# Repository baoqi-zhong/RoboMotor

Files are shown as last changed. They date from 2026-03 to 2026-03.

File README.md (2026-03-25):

# RoboMotor

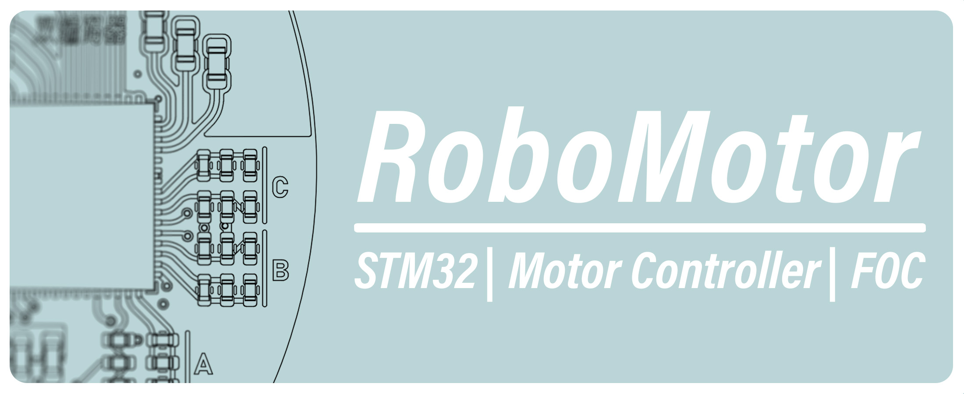
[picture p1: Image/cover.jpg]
Project cover


**English** | [中文版](./README_CN.md)

**RoboMotor** is an open-source FOC motor driver project. It provides integrated hardware designs and control algorithms for robotics applications.

## Key Features

- **Hardware Specs**: 4-to-6 layer PCBs designed for 20A-40A continuous current at 24V.
- **Control Algorithm**: Field-Oriented Control (FOC) with current, speed, and position loops.
- **Validation**: Designs tested in RoboMaster environments.

## Hardware

Designed with **KiCad 8**.
For detailed specifications, schematics, and measured performance, please visit the [Hardware](./Hardware/README.md) directory or click on a specific project below.

| Project Name | Target Motor | Key Specs | Core |
| :--- | :--- | :--- | :--- |
| [**RoboMotor-DJI-M3508**](./Hardware/RoboMotor-DJI-M3508/) | [DJI M3508](https://www.robomaster.com/en-US/products/components/general/M3508) | **24V 20A**, 6-Layer, Sin/Cos Encoder | STSPIN32G4 |
| [**RoboMotor-GIM6010-V2**](./Hardware/RoboMotor-GIM6010-V2/) | [GIM6010-8](https://steadywin-motor.com/products/built-in-star-gear-motor-motor-robot-joint-driver-actuator-controller-motor) | **24V 40A**, Dual Encoder Support | STSPIN32G4 |
| [**RoboMotor-GIM6010-V2-Encoder**](./Hardware/RoboMotor-GIM6010-V2-Encoder/) | GIM6010-8 | Magnetic Output Encoder PCB | MA730 |
| [**RoboMotor-GIM6010**](./Hardware/RoboMotor-GIM6010/) | GIM6010-8 | *Legacy Reference Design* | STM32G431 + FD6288 |

## Software

The FOC control algorithm is developed for the **STM32G4** series.

### Features
- **FOC Implementation**: Sensor-based Field-Oriented Control with Flux/Torque decoupling and BEMF feedforward compensation.
- **Control Loops**: 17Khz inner Current loop + outer 4Khz Speed loop + 1Khz Position loop.
- **Connectivity**:
  - **CAN Bus**: Compatible with DJI RoboMaster protocols (M3508/C620).
  - **Custom Protocol**: Extended commands for parameter tuning and telemetry.
- **Additional Functions**:
  - **Auto-Calibration**: Routines for encoder offset and motor parameter identification.
  - **Safety Mechanisms**: Error handling (Over-current, Over/under voltage, Over-temp) with auto-recovery modes.
  - **Feedback Support**: Support for SPI magnetic encoders and analog inputs.

*Find the source code and documentation in the `Software/` directory.*

## License

This project is released under the MIT License.  
See [LICENSE](./LICENSE) for details.

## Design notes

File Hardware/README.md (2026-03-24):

# RoboMotor Hardware
# Open-sourced FOC Driver PCB

All projects are designed with Kicad 8.

## Project List

|Name|Target Motor|Description|MCU/Chip|
|:--|:--|:--|:--|
|RoboMotor-DJI-M3508|[DJI M3508](https://www.robomaster.com/en-US/products/components/general/M3508)|6 Layer, High power density|STSPIN32G4|
|RoboMotor-GIM6010-V2|[GIM6010-8](https://steadywin-motor.com/products/built-in-star-gear-motor-motor-robot-joint-driver-actuator-controller-motor)|Support gear box output encoder|STSPIN32G4|
|RoboMotor-GIM6010-V2-Encoder|GIM6010-8|PCB of the output encoder|MA730|
|RoboMotor-GIM6010|GIM6010-8|Old version, reference only|STM32G431 + FD6288|

### RoboMotor-DJI-M3508

- Operating conditions: 24V, max 20A.
- MCU: STSPIN32G4. With integrated buck, LDO, Mosfet drivers and STM32G431 MCU.
- 6 Layer PCB, separate analog sampling circuit and power stage signals.
- Supports Sin/Cos encoder and CAN communication. Fully compatible with [DJI C620](https://www.robomaster.com/en-US/products/components/general/M3508) ESC.

Schematic:
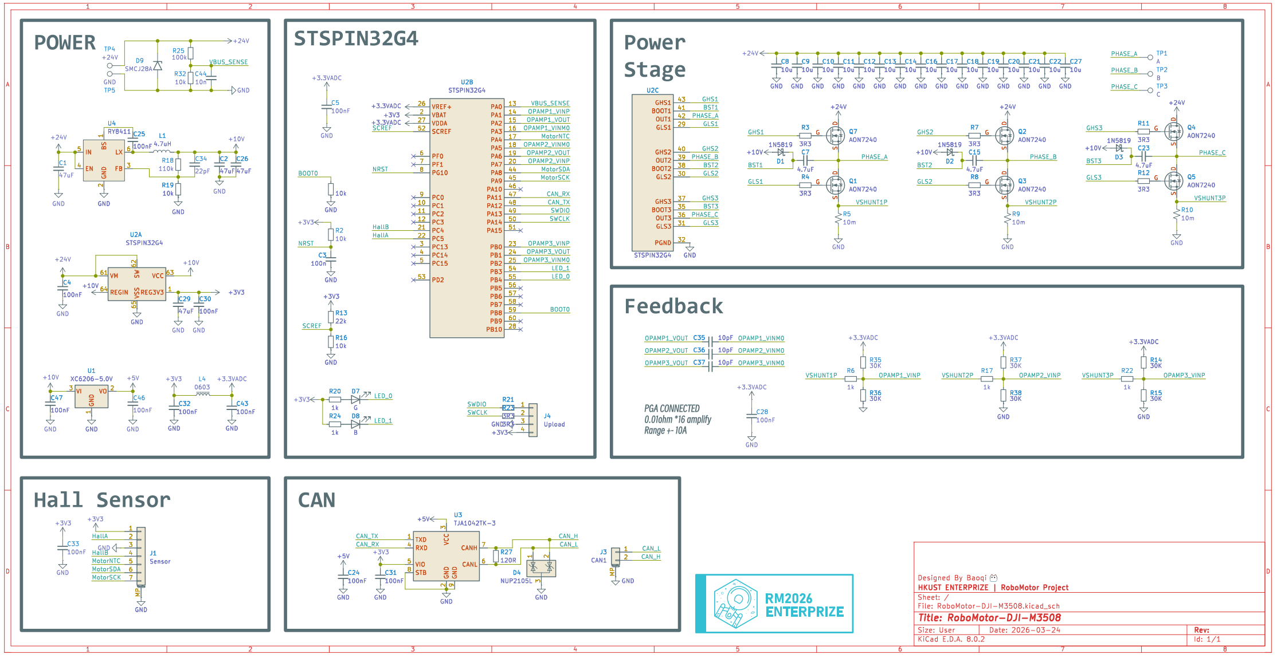
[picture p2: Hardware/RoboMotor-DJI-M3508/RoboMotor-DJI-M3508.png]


### RoboMotor-GIM6010-V2

- Operating conditions: 24V, max 40A.
- MCU: STSPIN32G4. With integrated buck, LDO, Mosfet drivers and STM32G431 MCU.
- Encoder: MA732 magnetic encoder
- 4 Layer PCB.
- Supports MA732 magnetic encoder, second encoder after gear box and CAN communication. Specifically designed for [GIM6010-8](https://steadywin-motor.com/products/built-in-star-gear-motor-motor-robot-joint-driver-actuator-controller-motor) motor with 8:1 reduction ratio.

Schematic:
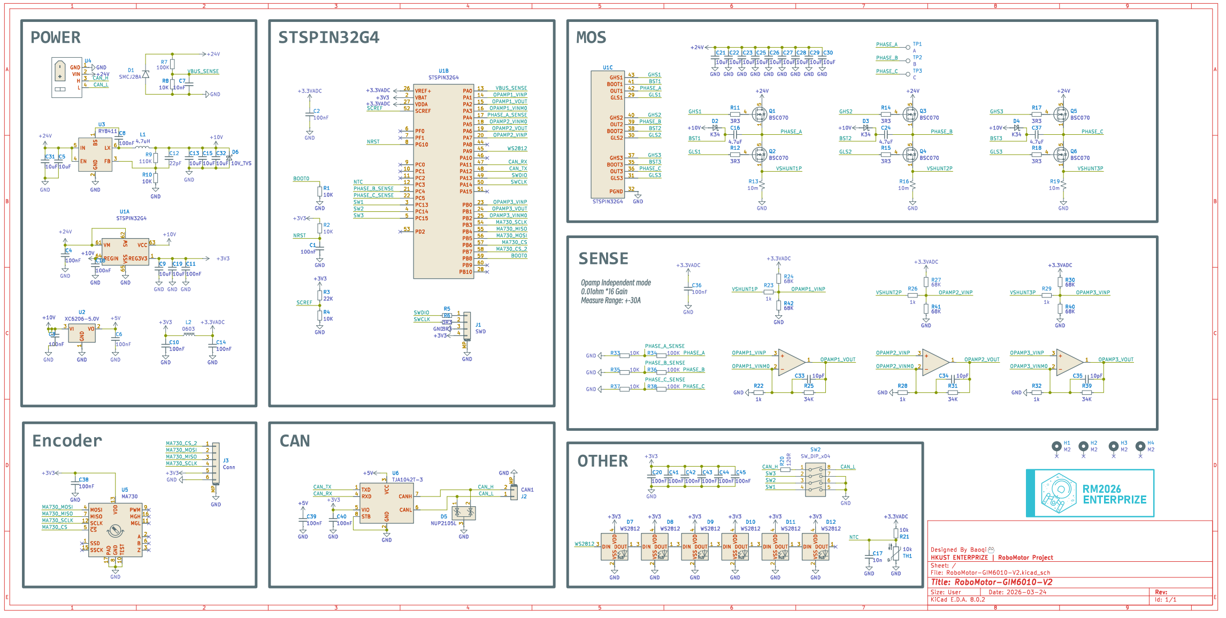
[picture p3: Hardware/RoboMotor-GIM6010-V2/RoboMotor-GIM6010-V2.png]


### RoboMotor-GIM6010
Lagecy version, for reference only.

- Operating conditions: 24V, max 40A.
- MCU: STM32G431CBU6. Mosfet driver: FD6288.
- Encoder: MA732 magnetic encoder
- 4 Layer PCB.
- Supports MA732 magnetic encoder, second encoder after gear box and CAN communication. Specifically designed for [GIM6010-8](https://steadywin-motor.com/products/built-in-star-gear-motor-motor-robot-joint-driver-actuator-controller-motor) motor with 8:1 reduction ratio.

Schematic:
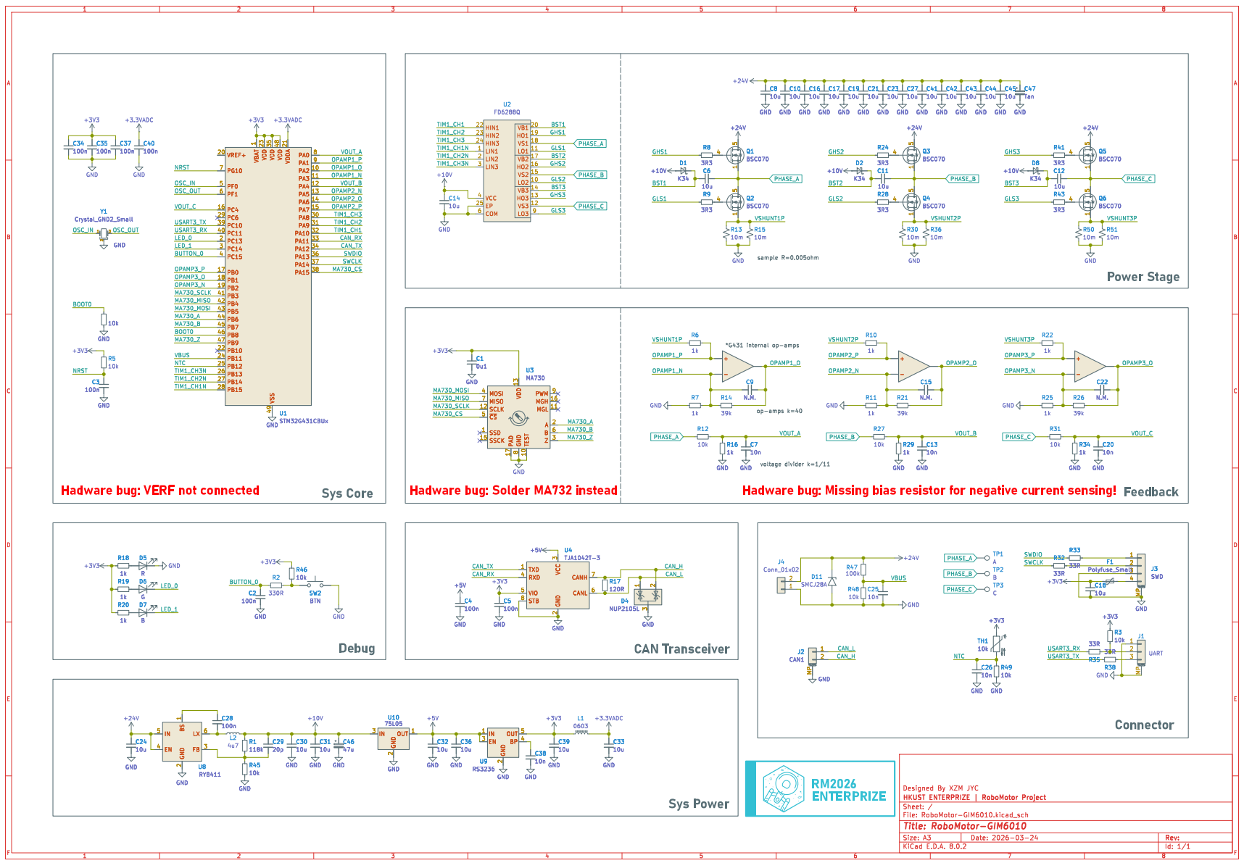
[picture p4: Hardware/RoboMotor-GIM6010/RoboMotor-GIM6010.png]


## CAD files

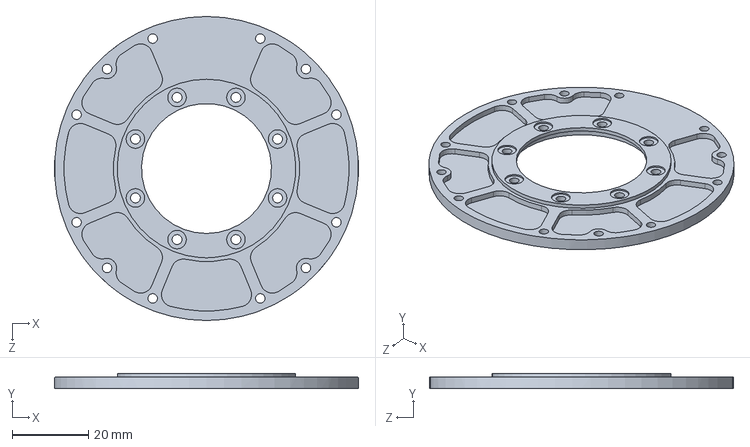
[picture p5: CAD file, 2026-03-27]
Mechanical/GIM6010/CNC_TOP.SLDPRT
80.0 x 4.00 x 80.0 mm

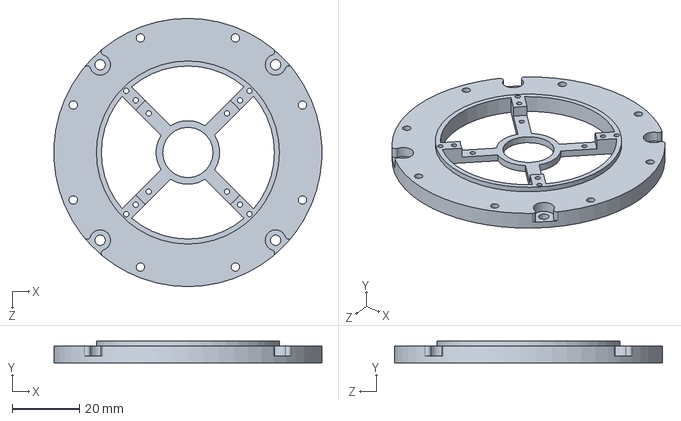
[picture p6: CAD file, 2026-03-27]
Mechanical/GIM6010/CNC_BOT.SLDPRT
79.9 x 6.50 x 80.0 mm

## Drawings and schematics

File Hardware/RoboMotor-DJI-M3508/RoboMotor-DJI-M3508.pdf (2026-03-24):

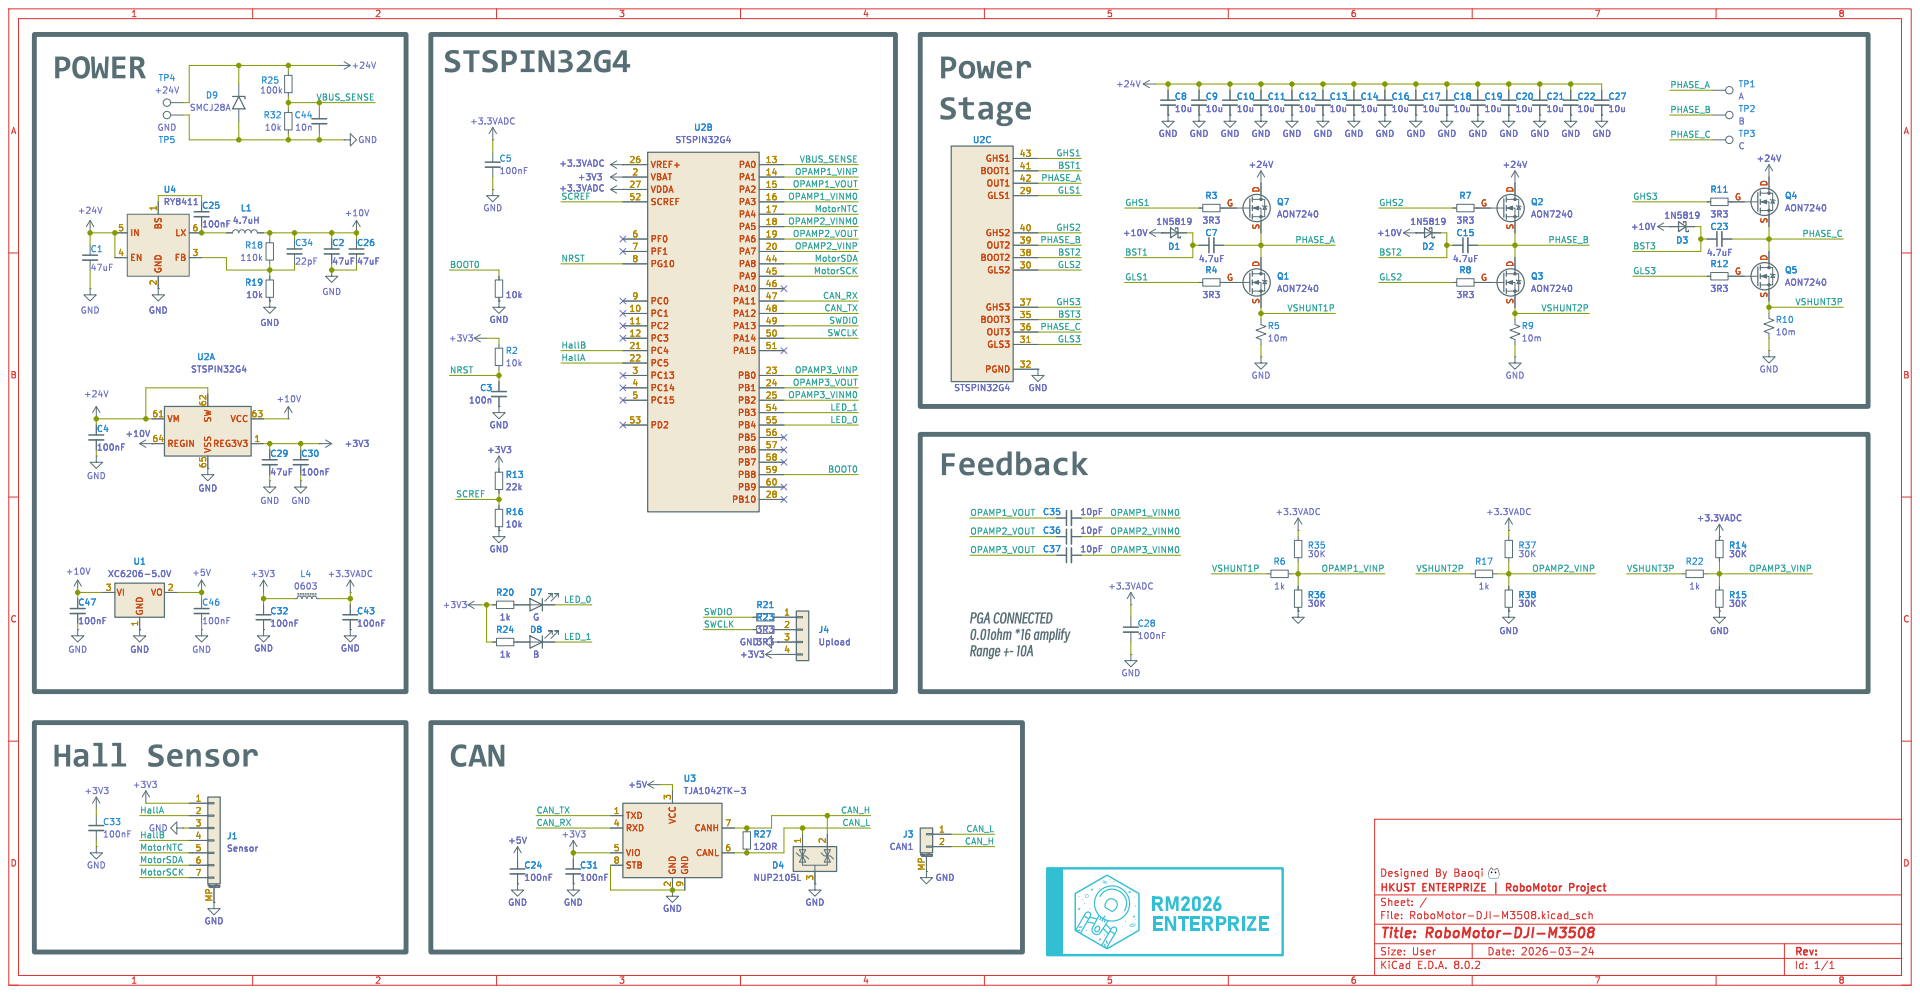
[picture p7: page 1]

CAN_RX MotorSCK MotorSDA CAN_TX OPAMP2_VOUT OPAMP2_VINM0 OPAMP3_VINP Hall Sensor

3 RXD 4 VIO 5 CANL 6 CANH 7 STB 8 GND

Id: 1/1 Title: RoboMotor-DJI-M3508

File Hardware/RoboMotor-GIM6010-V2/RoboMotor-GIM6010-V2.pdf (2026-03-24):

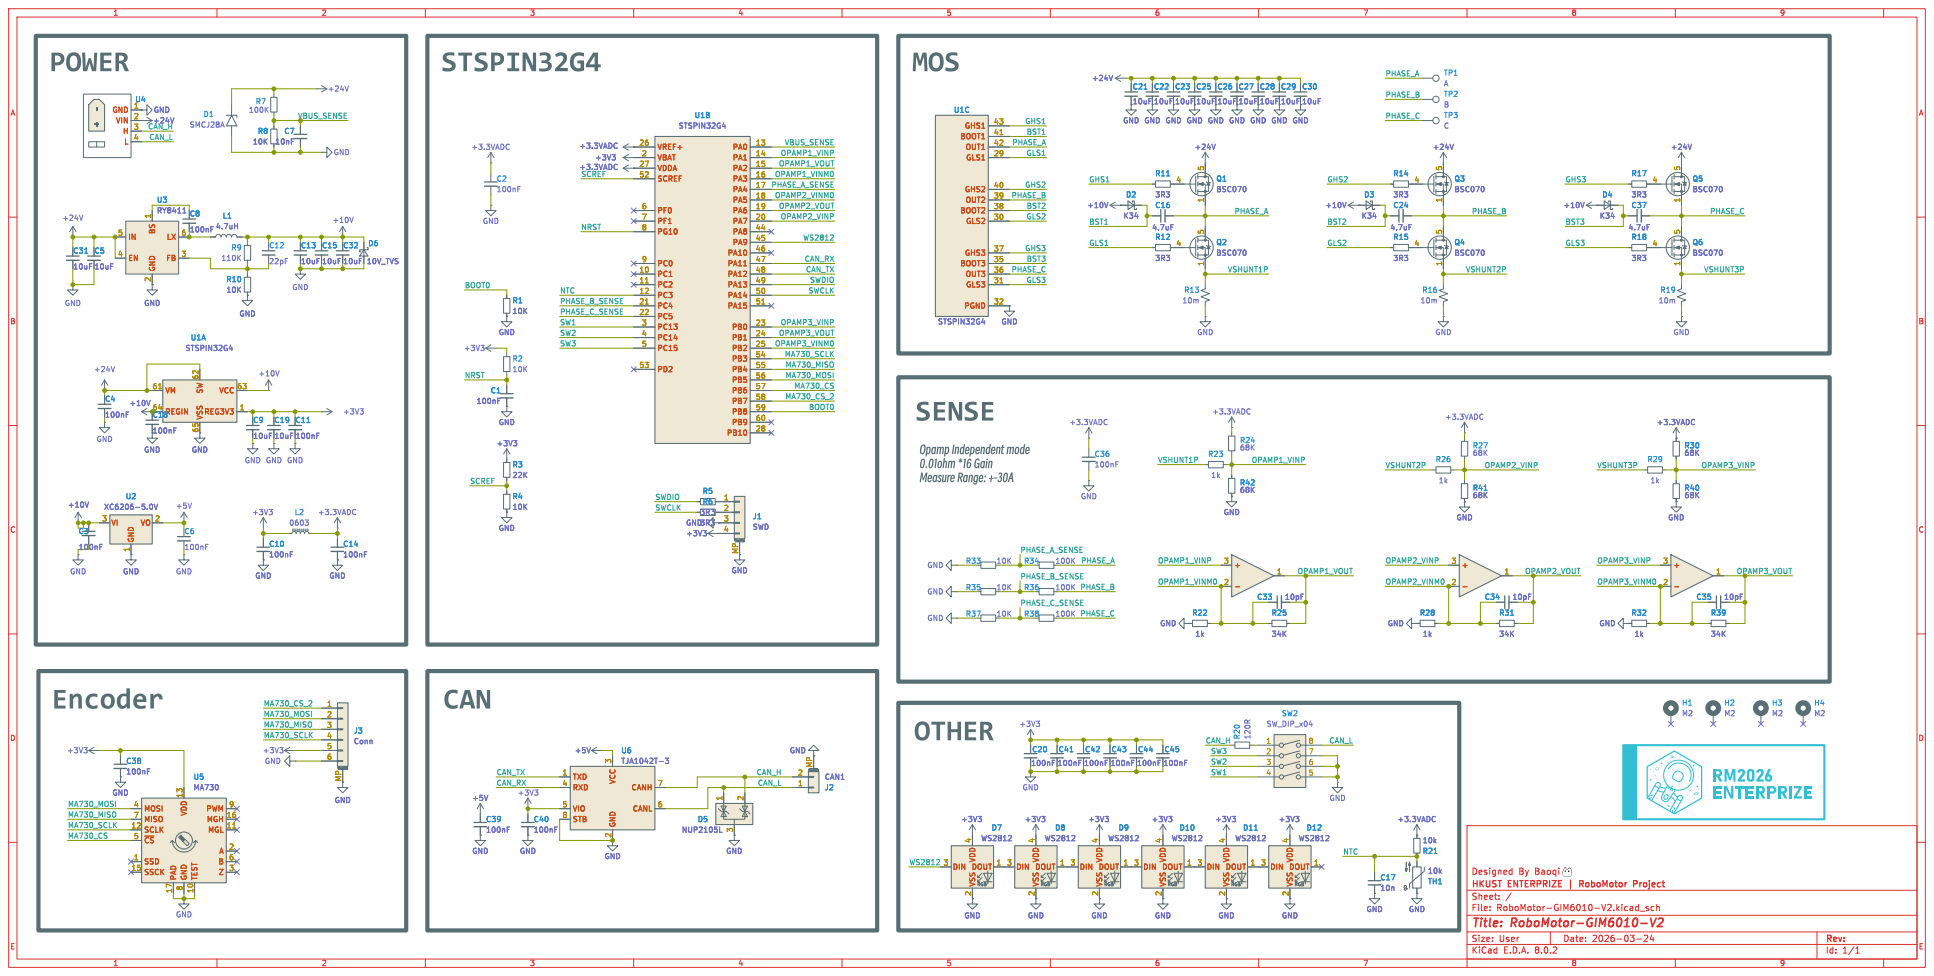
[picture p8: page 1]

3 RXD 4 VIO 5 CANL 6 CANH 7 STB 8 +5V GND

3 RXD 4 VIO 5 CANL 6 CANH 7 STB 8 U6 TJA1042T-3 +5V

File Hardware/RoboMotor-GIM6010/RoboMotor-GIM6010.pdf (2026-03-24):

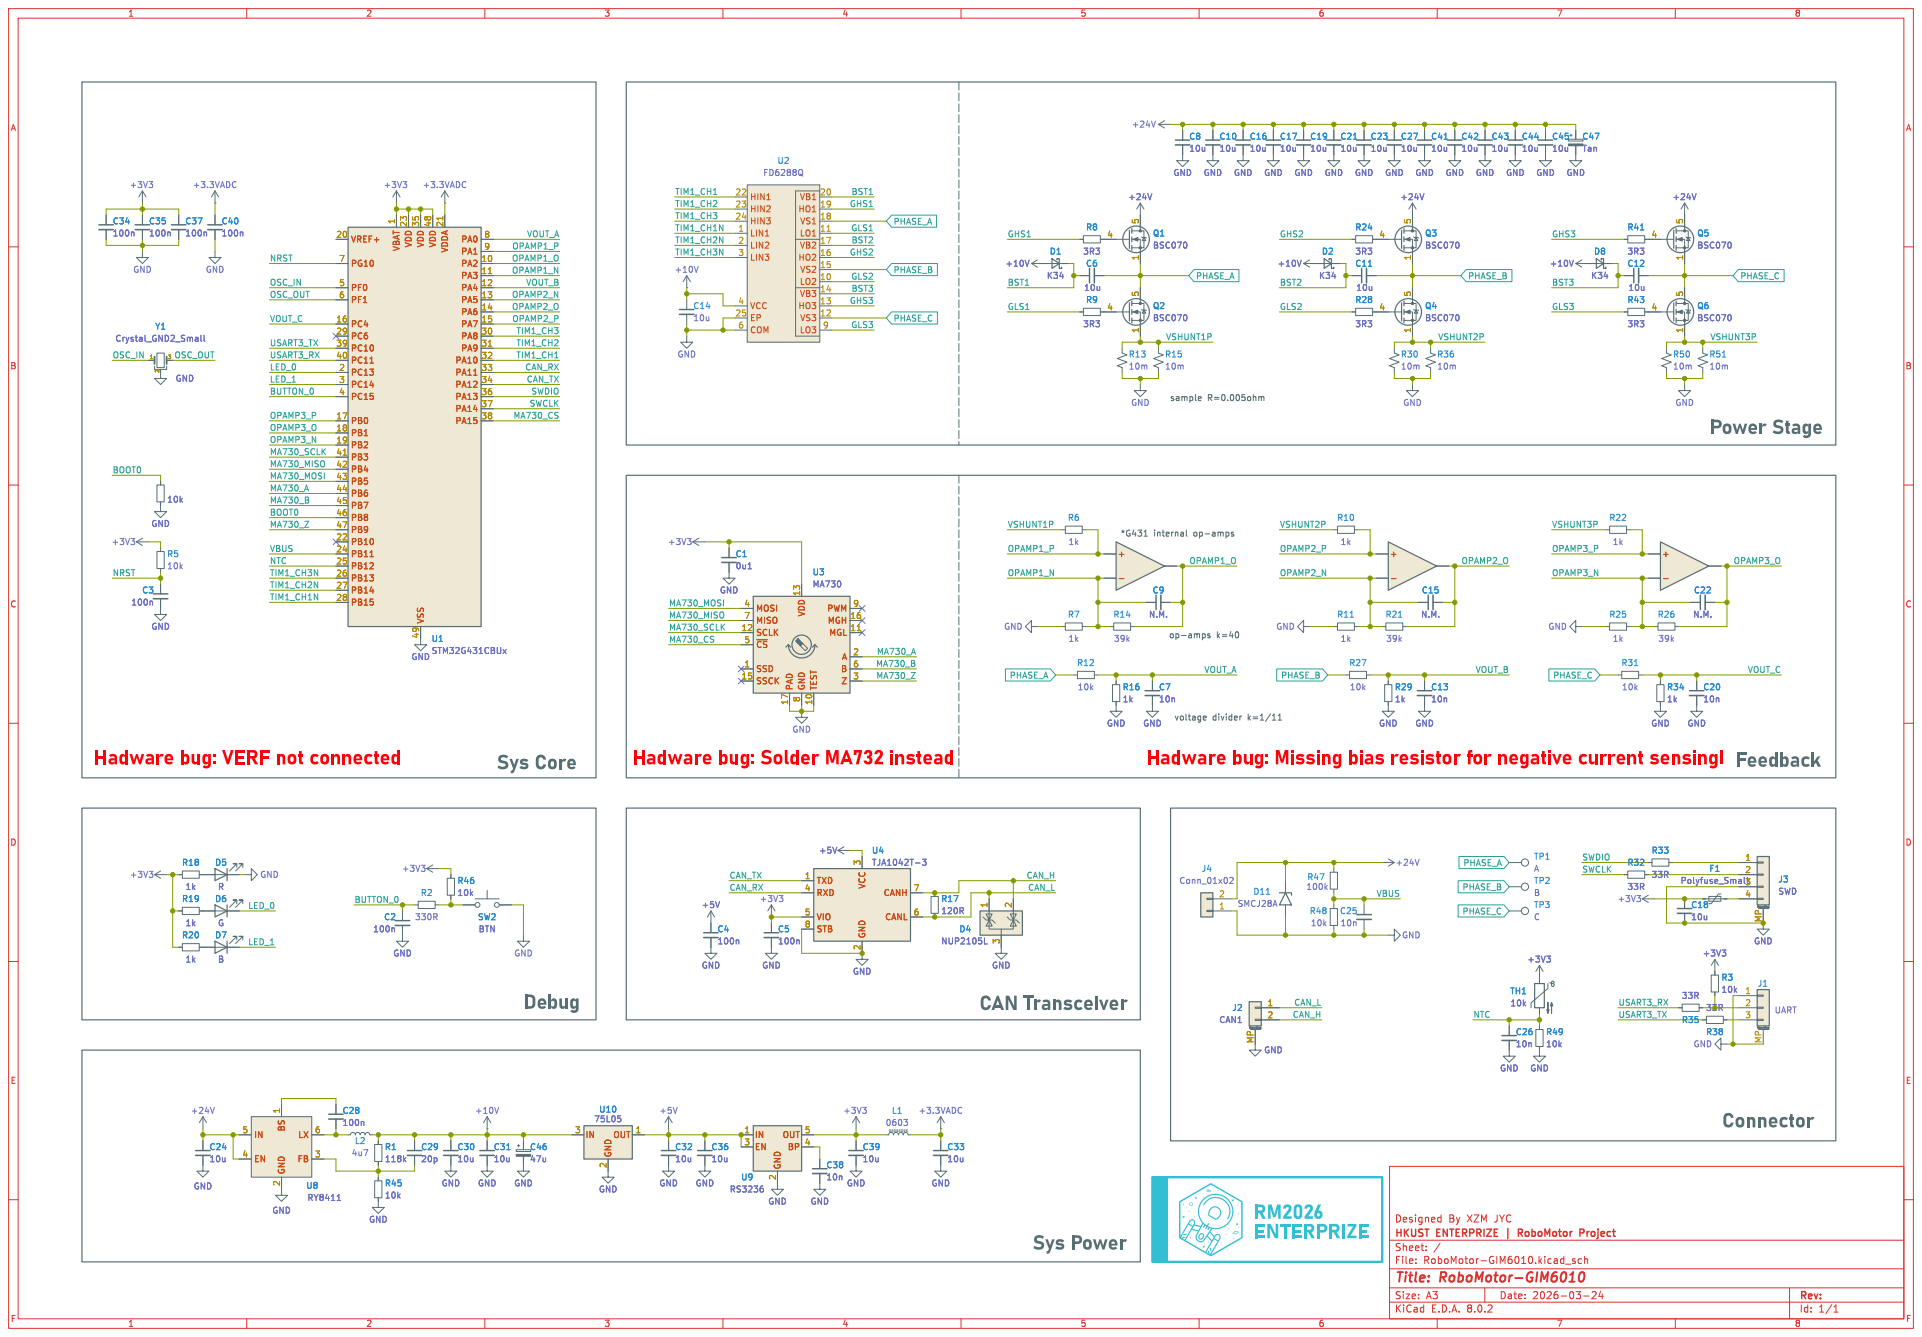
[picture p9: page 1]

1 PA2 10 PA3 11 PA4 12 PA5 13 PA6 14 PA7 15 PC4 16 PB0 17 PB1 18 PB2 19 PC13 2 VREF+ 20 VDDA 21 PB10 22 VDD 23 PB11 24 PB12 25 PB13 26 PB14 27 PB15 28 PC6 29 PC14 3 PA8 30 PA9 31 PA10 32 PA11 33 PA12 34 VDD 35 PA13 36 PA14 37 PA15 38 PC10 39 PC15 4 PC11 40 PB3 41 PB4 42 PB5 43 PB6 44 PB7 45 PB8 46 PB9 47 VDD 48 VSS 49 PF0 5 PF1 6 PG10 7 PA0 8 PA1 9 Y1 Crystal_GND2_Small 1

1 PA2 10 PA3 11 PA4 12 PA5 13 PA6 14 PA7 15 PC4 16 PB0 17 PB1 18 PB2 19 PC13 2 VREF+ 20 VDDA 21 PB10 22 VDD 23 PB11 24 PB12 25 PB13 26 PB14 27 PB15 28 PC6 29 PC14 3 PA8 30 PA9 31 PA10 32 PA11 33 PA12 34 VDD 35 PA13 36 PA14 37 PA15 38 PC10 39 PC15 4 PC11 40 PB3 41 PB4 42 PB5 43 PB6 44 PB7 45 PB8 46 PB9 47 VDD 48 VSS 49 PF0 5 PF1 6 PG10 7 PA0 8 PA1 9 U1STM32G431CBUx R5

Hadwarebug:Missingbiasresistorfor negativecurrent sensing!

3 RXD 4 VIO 5 CANL 6 CANH 7 STB 8 U4 TJA1042T-3

3 RXD 4 VIO 5 CANL 6 CANH 7 STB 8 D4 NUP2105L 3

2 EN 3 BP 4 OUT 5 U9 RS3236 GND GND
10u GND

2 EN 3 BP 4 OUT 5 GND GND

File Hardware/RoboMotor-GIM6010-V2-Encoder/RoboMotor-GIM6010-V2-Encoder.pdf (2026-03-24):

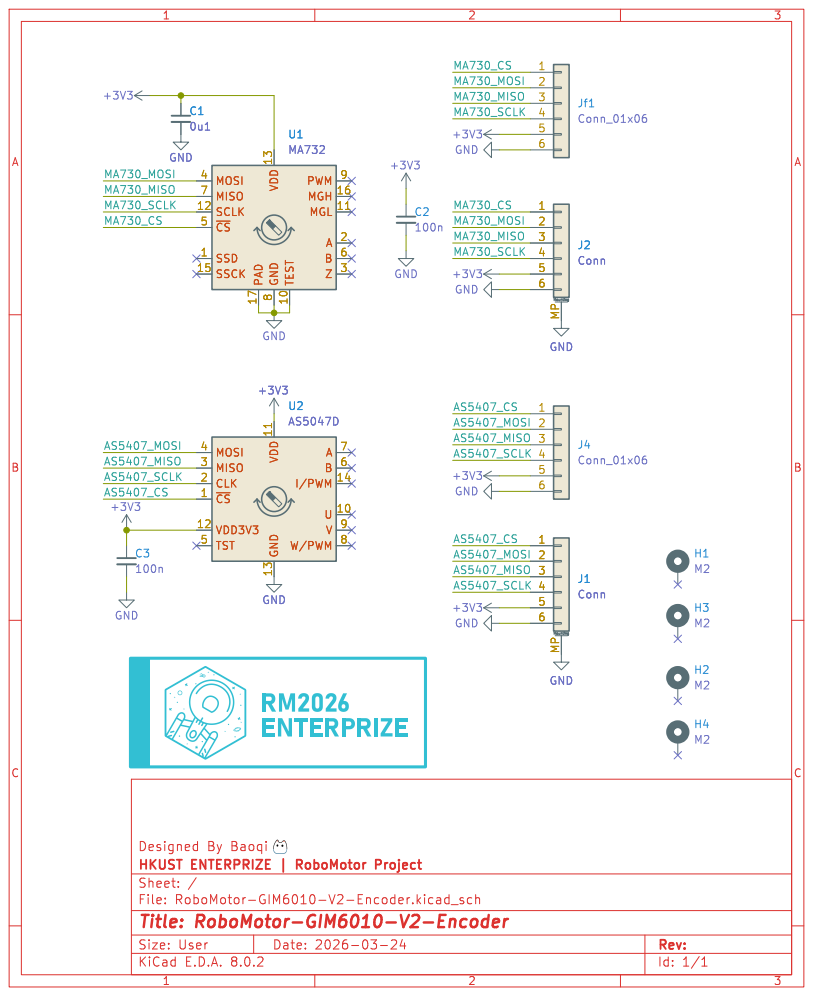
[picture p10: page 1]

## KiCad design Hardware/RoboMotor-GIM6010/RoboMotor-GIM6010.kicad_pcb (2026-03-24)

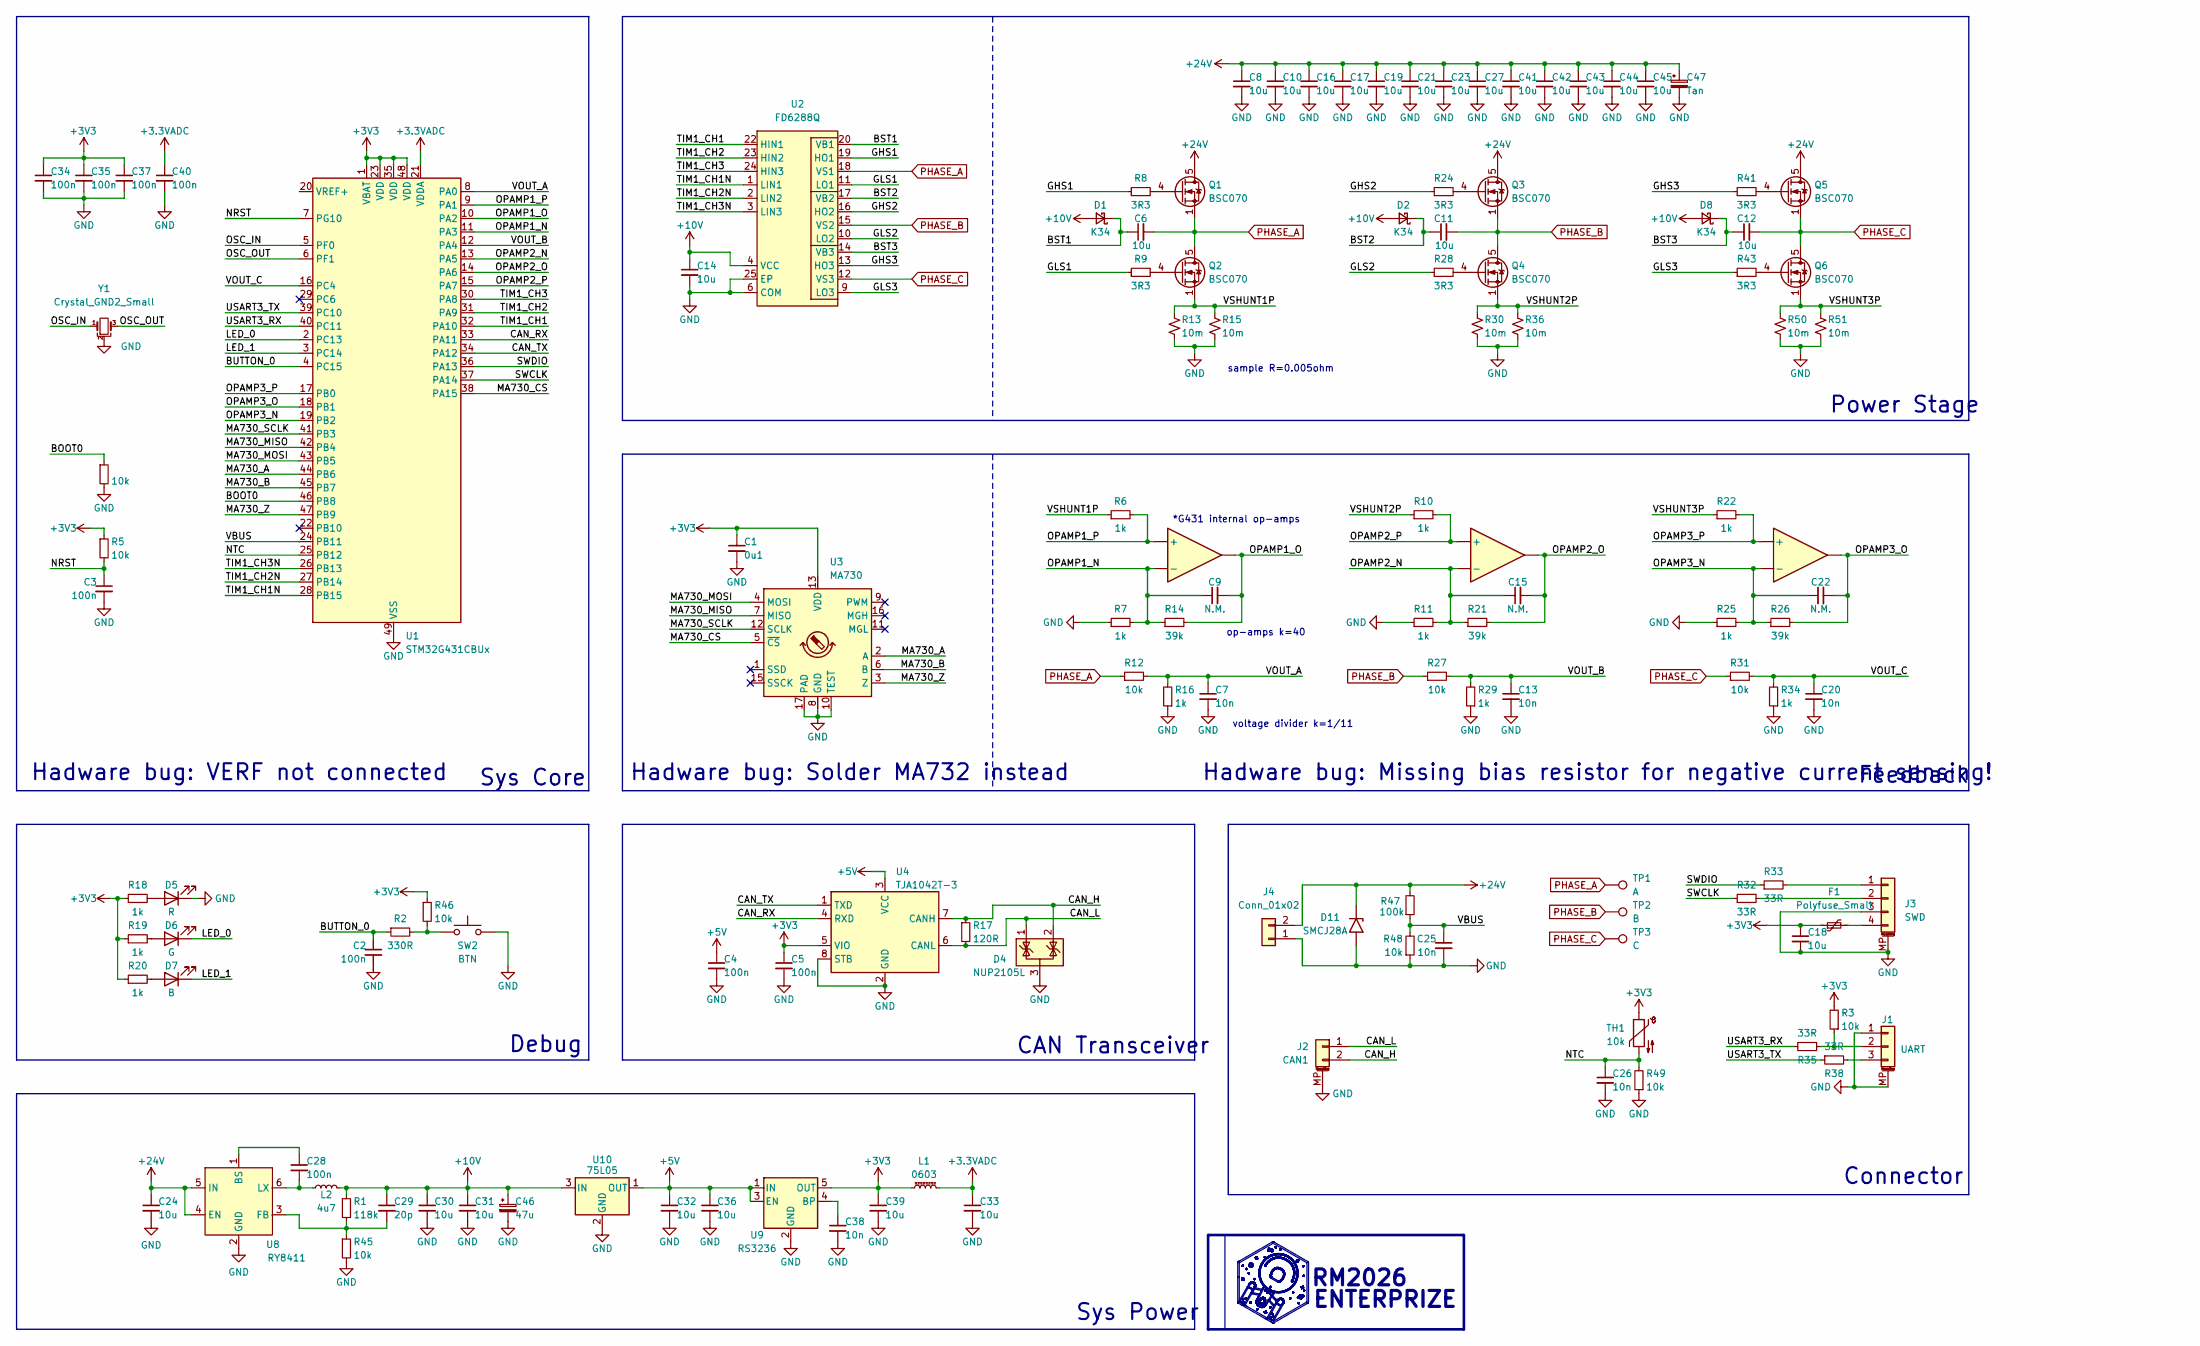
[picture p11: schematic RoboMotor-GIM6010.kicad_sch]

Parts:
C1: 0u1; C_0603_1608Metric
C2, C3, C4, C5, C28, C34, C35, C37, C40: 100n; C_0603_1608Metric
C6, C11, C12, C14, C18, C32, C33, C36, C39: 10u; C_0603_1608Metric
C7, C13, C20, C25, C26, C38: 10n; C_0603_1608Metric
C8, C10, C16, C17, C19, C21, C23, C24, C27, C30, C31, C41, C42, C43, C44, C45: 10u; C_1206_3216Metric
C9, C15, C22: N.M.; C_0603_1608Metric
C29: 20p; C_0603_1608Metric
C46: 47u; CP_EIA-3216-18_Kemet-A_Pad1.58x1.35mm_HandSolder
C47: Tan; CP_EIA-7343-30_AVX-N
D1, D2, D8: K34; D_SOD-323_HandSoldering
D4: NUP2105L; SOT-23
D5: R; LED_Side_0802
D6: G; LED_Side_0802
D7: B; LED_Side_0802
D11: SMCJ28A; D_SMC
F1: Polyfuse_Small; Fuse_1206_3216Metric
J1: UART; JST_GH_SM03B-GHS-TB_1x03-1MP_P1.25mm_Horizontal
J2: CAN1; JST_GH_SM02B-GHS-TB_1x02-1MP_P1.25mm_Horizontal
J3: SWD; Molex_PicoBlade_53261-0471_1x04-1MP_P1.25mm_Horizontal
J4: Conn_01x02; AMASS_XT30PW-M_1x02_P2.50mm_Horizontal
L1: 0603; L_0603_1608Metric
L2: 4u7; L_Sunlord_MWSA0402S
Q1, Q2, Q3, Q4, Q5, Q6: BSC070; TDSON-8-1
R1: 118k; R_0603_1608Metric
R2: 330R; R_0603_1608Metric
R3, R4, R5, R12, R27, R31, R45, R46, R48, R49: 10k; R_0603_1608Metric
R6, R7, R10, R11, R16, R18, R19, R20, R22, R25, R29, R34: 1k; R_0603_1608Metric
R8, R9, R24, R28, R41, R43: 3R3; R_0603_1608Metric
R13, R15, R30, R36, R50, R51: 10m; R_1206_3216Metric
R14, R21, R26: 39k; R_0603_1608Metric
R17: 120R; R_0603_1608Metric
R32, R33, R35, R38: 33R; R_0603_1608Metric
R47: 100k; R_0603_1608Metric
SW2: BTN; Panasonic_EVQPUL_EVQPUC
TH1: 10k; TestPoint_2Pads_Pitch2.54mm_Drill0.8mm
TP1: A; TestPoint_Pad_4.0x4.0mm
TP2: B; TestPoint_Pad_4.0x4.0mm
TP3: C; TestPoint_Pad_4.0x4.0mm
U1: STM32G431CBUx; QFN-48-1EP_7x7mm_P0.5mm_EP5.6x5.6mm
U2: FD6288Q; QFN-24-1EP_4x4mm_P0.5mm_EP2.7x2.7mm
U3: MA730; QFN-16-1EP_3x3mm_P0.5mm_EP1.75x1.75mm
U4: TJA1042T-3; SOIC-8_3.9x4.9mm_P1.27mm
U5, U6, U7: type="X" model="OPAMP" lib=""
U8: RY8411; SOT-23-6
U9: RS3236; SOT-23-5
U10: 75L05; SOT-89-3
Y1: Crystal_GND2_Small; Resonator_SMD_Murata_CSTxExxV-3Pin_3.0x1.1mm

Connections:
+3.3VADC: C33.1, C40.1, L1.2, U1.21 (VDDA)
+3V3: C1.1, C5.1, C18.1, C34.1, C35.1, C37.1, C39.1, F1.1, L1.1, R3.2, R5.1, R18.1, R19.1, R20.1, R46.1, TH1.1, U1.1 (VBAT), U1.23 (VDD), U1.35 (VDD), U1.48 (VDD), U3.13 (VDD), U4.5 (VIO), U9.5 (OUT)
+5V: C4.1, C32.1, C36.1, U4.3 (VCC), U9.1 (IN), U9.3 (EN), U10.1 (OUT)
+10V: C14.1, C29.1, C30.1, C31.1, C46.1, D1.2 (A), D2.2 (A), D8.2 (A), L2.2, R1.1, U2.4 (VCC), U10.3 (IN)
+24V: C8.1, C10.1, C16.1, C17.1, C19.1, C21.1, C23.1, C24.1, C27.1, C41.1, C42.1, C43.1, C44.1, C45.1, C47.1, D11.1 (A1), J4.2, Q1.5 (D), Q3.5 (D), Q5.5 (D), R47.2, U8.4 (EN), U8.5 (IN)
/BOOT0: R4.1, U1.46 (PB8)
/BST1: C6.1, D1.1 (K), U2.20 (VB1)
/BST2: C11.1, D2.1 (K), U2.17 (VB2)
/BST3: C12.1, D8.1 (K), U2.14 (VB3)
/BUTTON_0: C2.1, R2.1, U1.4 (PC15)
/CAN_H: D4.2 (K), J2.2, R17.1, U4.7 (CANH)
/CAN_L: D4.1 (K), J2.1, R17.2, U4.6 (CANL)
/CAN_RX: U1.33 (PA11), U4.4 (RXD)
/CAN_TX: U1.34 (PA12), U4.1 (TXD)
/GHS1: R8.1, U2.19 (HO1)
/GHS2: R24.1, U2.16 (HO2)
/GHS3: R41.1, U2.13 (HO3)
/GLS1: R9.1, U2.11 (LO1)
/GLS2: R28.1, U2.10 (LO2)
/GLS3: R43.1, U2.9 (LO3)
/LED_0: D6.1 (K), U1.2 (PC13)
/LED_1: D7.1 (K), U1.3 (PC14)
/MA730_A: U1.44 (PB6), U3.2 (A)
/MA730_B: U1.45 (PB7), U3.6 (B)
/MA730_CS: U1.38 (PA15), U3.5 (~CS)
/MA730_MISO: U1.42 (PB4), U3.7 (MISO)
/MA730_MOSI: U1.43 (PB5), U3.4 (MOSI)
/MA730_SCLK: U1.41 (PB3), U3.12 (SCLK)
/MA730_Z: U1.47 (PB9), U3.3 (Z)
/NRST: C3.1, R5.2, U1.7 (PG10)
/NTC: C26.1, R49.2, TH1.2, U1.25 (PB12)
/OPAMP1_N: C9.1, R7.2, R14.1, U1.11 (PA3), U5.
/OPAMP1_O: C9.2, R14.2, U1.10 (PA2), U5.
/OPAMP1_P: R6.2, U1.9 (PA1), U5.
/OPAMP2_N: C15.1, R11.2, R21.1, U1.13 (PA5), U6.
/OPAMP2_O: C15.2, R21.2, U1.14 (PA6), U6.
/OPAMP2_P: R10.2, U1.15 (PA7), U6.
/OPAMP3_N: C22.1, R25.2, R26.1, U1.19 (PB2), U7.
/OPAMP3_O: C22.2, R26.2, U1.18 (PB1), U7.
/OPAMP3_P: R22.2, U1.17 (PB0), U7.
/OSC_IN: U1.5 (PF0), Y1.1
/OSC_OUT: U1.6 (PF1), Y1.3
/SWCLK: R32.1, U1.37 (PA14)
/SWDIO: R33.1, U1.36 (PA13)
/TIM1_CH1: U1.32 (PA10), U2.22 (HIN1)
/TIM1_CH1N: U1.28 (PB15), U2.1 (LIN1)
/TIM1_CH2: U1.31 (PA9), U2.23 (HIN2)
/TIM1_CH2N: U1.27 (PB14), U2.2 (LIN2)
/TIM1_CH3: U1.30 (PA8), U2.24 (HIN3)
/TIM1_CH3N: U1.26 (PB13), U2.3 (LIN3)
/USART3_RX: R35.1, U1.40 (PC11)
/USART3_TX: R38.1, U1.39 (PC10)
/VBUS: C25.1, R47.1, R48.2, U1.24 (PB11)
/VOUT_A: C7.1, R12.2, R16.2, U1.8 (PA0)
/VOUT_B: C13.1, R27.2, R29.2, U1.12 (PA4)
/VOUT_C: C20.1, R31.2, R34.2, U1.16 (PC4)
/VSHUNT1P: Q2.1 (S), Q2.2 (S), Q2.3 (S), R6.1, R13.1, R15.1
/VSHUNT2P: Q4.1 (S), Q4.2 (S), Q4.3 (S), R10.1, R30.1, R36.1
/VSHUNT3P: Q6.1 (S), Q6.2 (S), Q6.3 (S), R22.1, R50.1, R51.1
GND: C1.2, C2.2, C3.2, C4.2, C5.2, C7.2, C8.2, C10.2, C13.2, C14.2, C16.2, C17.2, C18.2, C19.2, C20.2, C21.2, C23.2, C24.2, C25.2, C26.2, C27.2, C30.2, C31.2, C32.2, C33.2, C34.2, C35.2, C36.2, C37.2, C38.2, C39.2, C40.2, C41.2, C42.2, C43.2, C44.2, C45.2, C46.2, C47.2, D4.3 (A), D5.1 (K), D11.2 (A2), J1.1, J1.MP (MountPin), J2.MP (MountPin), J3.3, J3.MP (MountPin), J4.1, R4.2, R7.1, R11.1, R13.2, R15.2, R16.1, R25.1, R29.1, R30.2, R34.1, R36.2, R45.2, R48.1, R49.1, R50.2, R51.2, SW2.2, U1.49 (VSS), U2.6 (COM), U2.25 (EP), U3.8 (GND), U3.10 (TEST), U3.17 (PAD), U4.2 (GND), U4.8 (STB), U8.2 (GND), U9.2 (GND), U10.2 (GND), Y1.2
unnamed: D5.2 (A), R18.2
unnamed: D6.2 (A), R19.2
unnamed: D7.2 (A), R20.2
unnamed: J1.2, R3.1, R35.2
unnamed: J1.3, R38.2
unnamed: J3.1, R33.2
unnamed: J3.2, R32.2
unnamed: F1.2, J3.4
unnamed: Q1.4 (G), R8.2
unnamed: Q2.4 (G), R9.2
unnamed: Q3.4 (G), R24.2
unnamed: Q4.4 (G), R28.2
unnamed: Q5.4 (G), R41.2
unnamed: Q6.4 (G), R43.2
unnamed: R2.2, R46.2, SW2.1
unnamed: C28.1, U8.1 (BS)
unnamed: C29.2, R1.2, R45.1, U8.3 (FB)
unnamed: C28.2, L2.1, U8.6 (LX)
unnamed: C38.1, U9.4 (BP)
PHASE_A: C6.2, Q1.1 (S), Q1.2 (S), Q1.3 (S), Q2.5 (D), R12.1, TP1.1, U2.18 (VS1)
PHASE_B: C11.2, Q3.1 (S), Q3.2 (S), Q3.3 (S), Q4.5 (D), R27.1, TP2.1, U2.15 (VS2)
PHASE_C: C12.2, Q5.1 (S), Q5.2 (S), Q5.3 (S), Q6.5 (D), R31.1, TP3.1, U2.12 (VS3)

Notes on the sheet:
op-amps k=40
Hadware bug: VERF not connected
Hadware bug: Missing bias resistor for negative current sensing!
RM2026
Sys Power
CAN Transceiver
ENTERPRIZE
Connector
Hadware bug: Solder MA732 instead
sample R=0.005ohm
Sys Core
*G431 internal op-amps
Debug
voltage divider k=1/11
Power Stage
Feedback

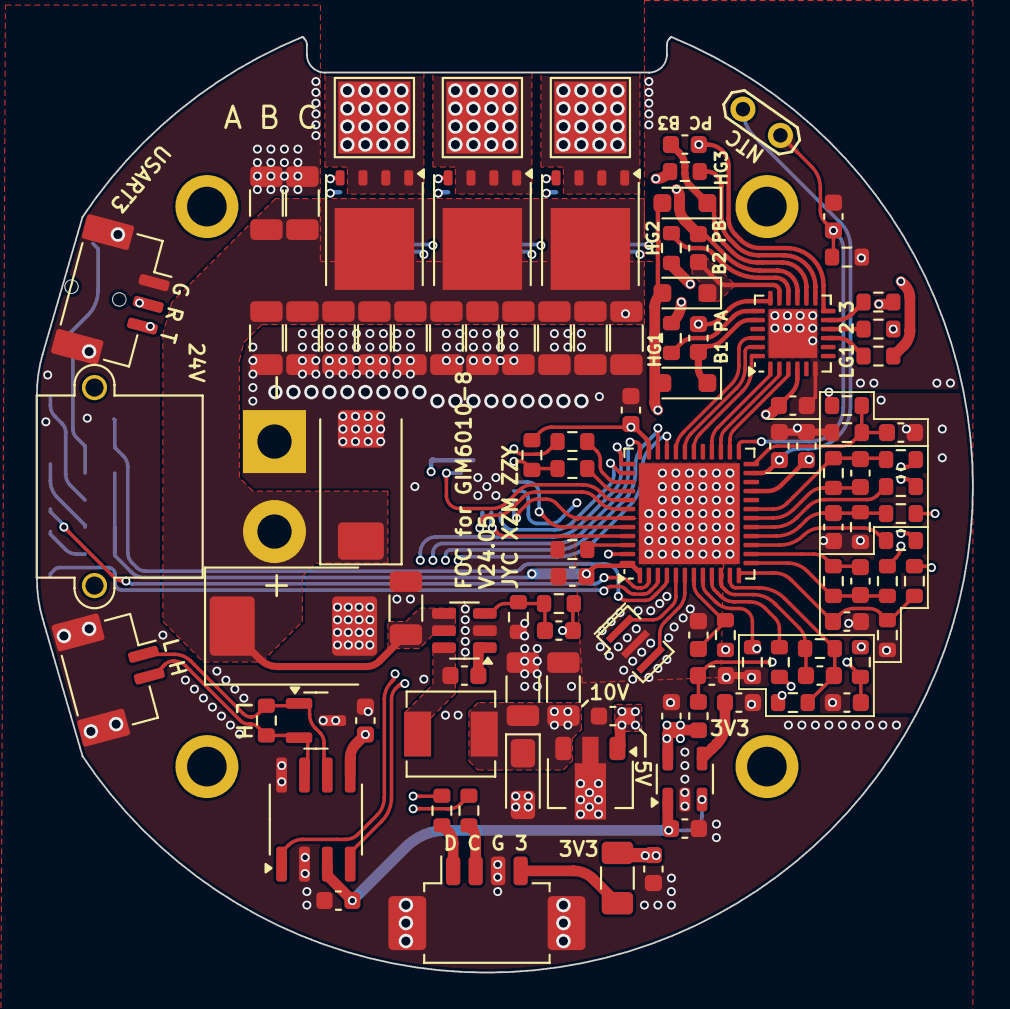
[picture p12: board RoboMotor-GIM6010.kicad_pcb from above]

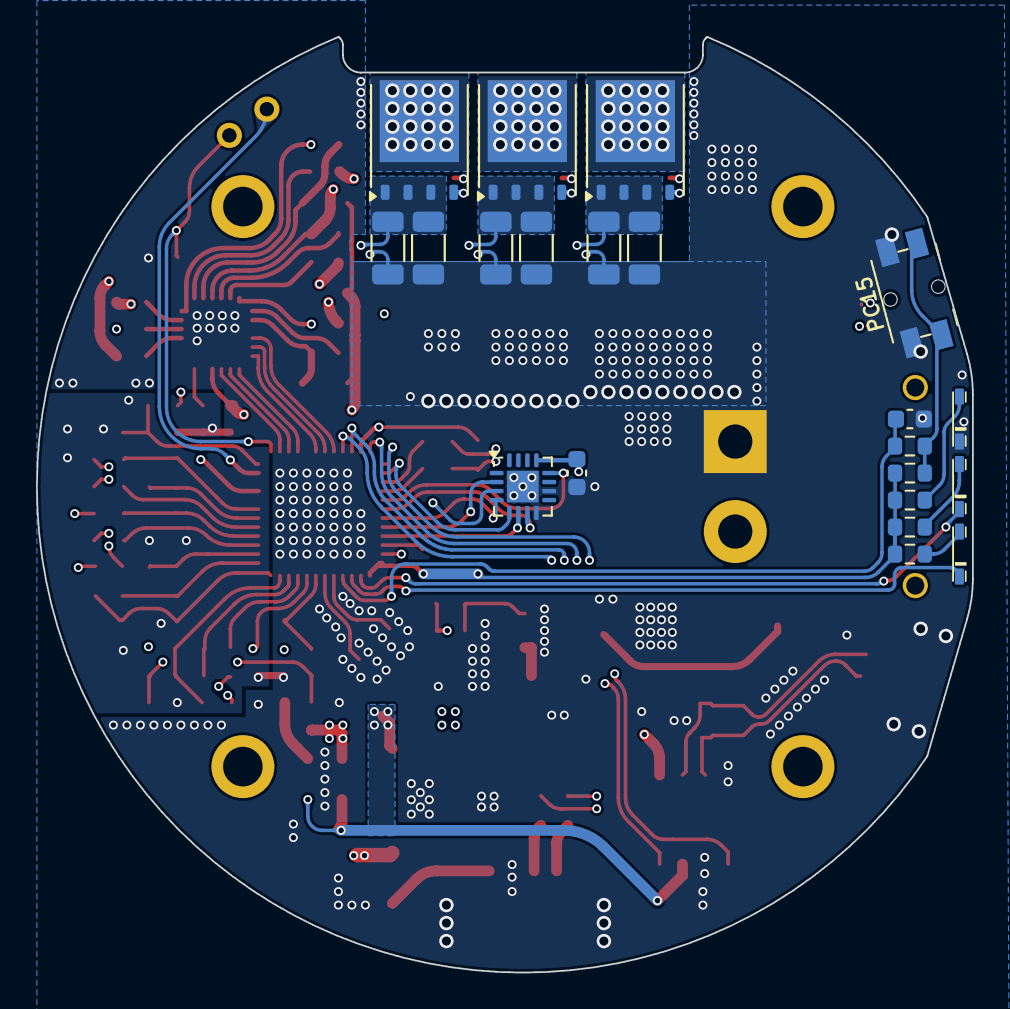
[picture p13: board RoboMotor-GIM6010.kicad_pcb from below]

Board: 4 copper layers, 52.0 x 52.0 mm, 130 parts (21 on the bottom side), 82 nets.

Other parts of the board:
H1, H2, H3, H4: MountingHole_Pad; MountingHole_2.2mm_M2_ISO7380_Pad

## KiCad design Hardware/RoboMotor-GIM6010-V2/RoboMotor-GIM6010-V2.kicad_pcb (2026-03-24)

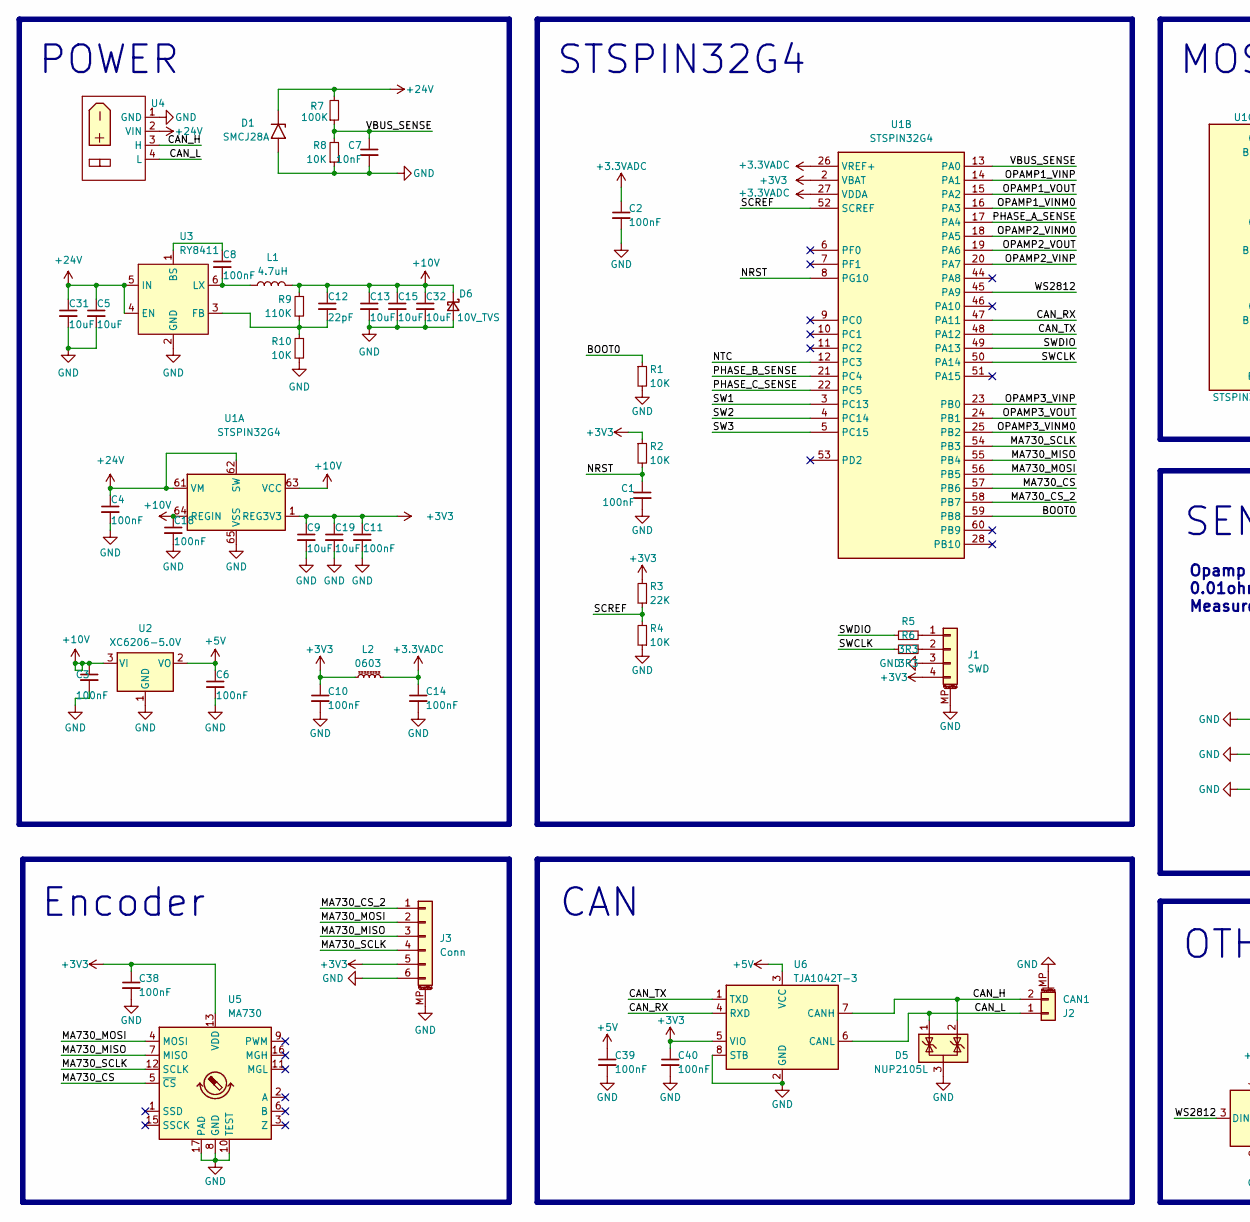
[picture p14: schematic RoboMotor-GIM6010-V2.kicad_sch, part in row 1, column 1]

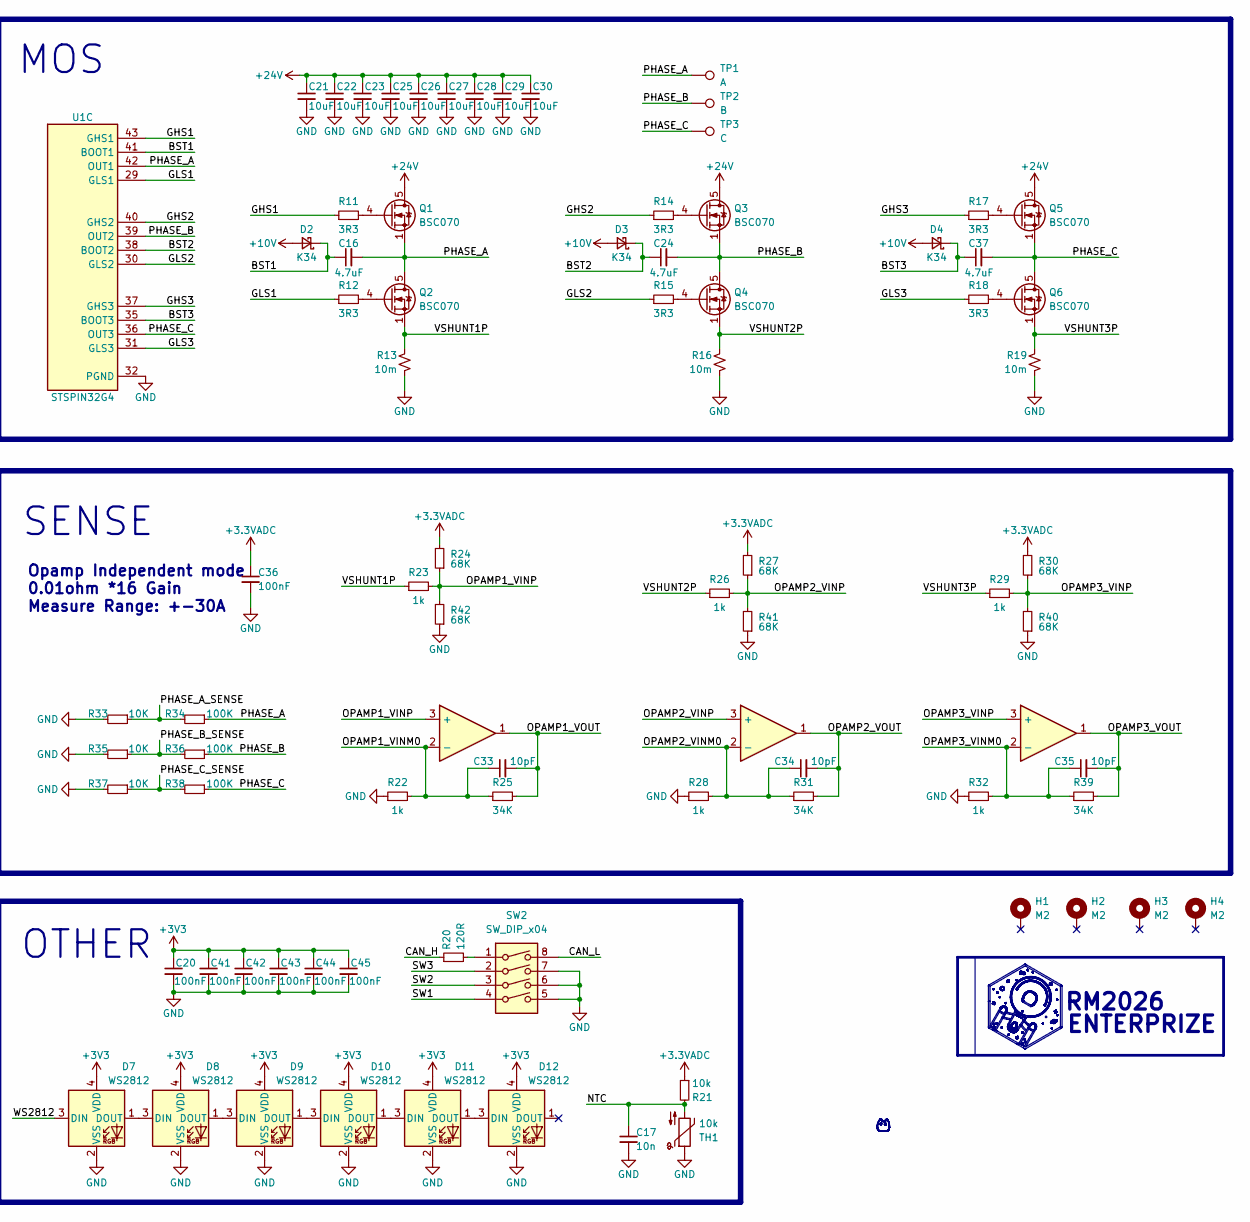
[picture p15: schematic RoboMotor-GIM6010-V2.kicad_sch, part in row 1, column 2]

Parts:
C1, C2, C3, C4, C6, C8, C10, C11, C14, C18, C20, C36, C38, C39, C40, C41, C42, C43, C44, C45: 100nF; C_0603_1608Metric
C5, C13, C15, C21, C22, C23, C25, C26, C27, C28, C29, C30, C31, C32: 10uF; C_1206_3216Metric
C7: 10nF; C_0603_1608Metric
C9, C19: 10uF; C_0603_1608Metric
C12: 22pF; C_0603_1608Metric
C16, C24, C37: 4.7uF; C_0603_1608Metric
C17: 10n; C_0603_1608Metric
C33, C34, C35: 10pF; C_0402_1005Metric
D1: SMCJ28A; D_SMA
D2, D3, D4: K34; D_SOD-323_HandSoldering
D5: NUP2105L; SOT-23
D6: 10V_TVS; D_SMF
D7, D8, D9, D10, D11, D12: WS2812; LED_WS2812B-2020_PLCC4_2.0x2.0mm
H1, H2, H3, H4: M2; MountingHole_2.2mm_M2_DIN965_Pad_TopBottom
J1: SWD; Molex_PicoBlade_53261-0471_1x04-1MP_P1.25mm_Horizontal
J2: CAN1; JST_GH_SM02B-GHS-TB_1x02-1MP_P1.25mm_Horizontal
J3: Conn; TE_0-1734839-6_1x06-1MP_P0.5mm_Horizontal
L1: 4.7uH; L_Neosid_SMS-ME3015
L2: 0603; L_0603_1608Metric
Q1, Q2, Q3, Q4, Q5, Q6: BSC070; TDSON-8-1
R1, R2, R4, R8, R10, R33, R35, R37: 10K; R_0603_1608Metric
R3: 22K; R_0603_1608Metric
R5, R6, R11, R12, R14, R15, R17, R18: 3R3; R_0603_1608Metric
R7, R34, R36, R38: 100K; R_0603_1608Metric
R9: 110K; R_0603_1608Metric
R13, R16, R19: 10m; R_2512_6332Metric
R20: 120R; R_0603_1608Metric
R21: 10k; R_0603_1608Metric
R22, R23, R26, R28, R29, R32: 1k; R_0402_1005Metric
R24, R27, R30, R40, R41, R42: 68K; R_0402_1005Metric
R25, R31, R39: 34K; R_0402_1005Metric
SW2: SW_DIP_x04; SW_DIP_SPSTx04_Slide_Copal_CHS-04B_W7.62mm_P1.27mm
TH1: 10k; TestPoint_2Pads_Pitch2.54mm_Drill0.8mm
TP1: A; TestPoint_Pad_4.0x4.0mm
TP2: B; TestPoint_Pad_4.0x4.0mm
TP3: C; TestPoint_Pad_4.0x4.0mm
U1: STSPIN32G4; QFN-64-1EP_9x9mm_P0.5mm_EP4.35x4.35mm
U2: XC6206-5.0V; SOT-23-3
U3: RY8411; SOT-23-6
U4: AMASS_XT30PW(2+2)-M_1x02_P2.50mm_Horizontal
U5: MA730; QFN-16-1EP_3x3mm_P0.5mm_EP1.75x1.75mm
U6: TJA1042T-3; SOIC-8_3.9x4.9mm_P1.27mm
U7, U8, U9: (no value)

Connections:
+3.3VADC: C2.1, C14.1, C36.1, L2.2, R21.1, R24.2, R27.2, R30.2, U1.26 (VREF+), U1.27 (VDDA)
+3V3: C9.1, C10.1, C11.1, C19.1, C20.1, C38.1, C40.1, C41.1, C42.1, C43.1, C44.1, C45.1, D7.4 (VDD), D8.4 (VDD), D9.4 (VDD), D10.4 (VDD), D11.4 (VDD), D12.4 (VDD), J1.4, J3.5, L2.1, R2.1, R3.2, U1.1 (REG3V3), U1.2 (VBAT), U5.13 (VDD), U6.5 (VIO)
+5V: C6.1, C39.1, U2.2 (VO), U6.3 (VCC)
+10V: C3.1, C12.1, C13.1, C15.1, C18.1, C32.1, D2.2 (A), D3.2 (A), D4.2 (A), D6.1 (K), L1.2, R9.1, U1.63 (VCC), U1.64 (REGIN), U2.3 (VI)
+24V: C4.1, C5.1, C21.1, C22.1, C23.1, C25.1, C26.1, C27.1, C28.1, C29.1, C30.1, C31.1, D1.1 (A1), Q1.5 (D), Q3.5 (D), Q5.5 (D), R7.2, U1.61 (VM), U1.62 (SW), U3.4 (EN), U3.5 (IN), U4.2 (VIN)
/BOOT0: R1.1, U1.59 (PB8)
/BST1: C16.1, D2.1 (K), U1.41 (BOOT1)
/BST2: C24.1, D3.1 (K), U1.38 (BOOT2)
/BST3: C37.1, D4.1 (K), U1.35 (BOOT3)
/CAN_H: D5.2 (K), J2.2, R20.1, U4.3 (H), U6.7 (CANH)
/CAN_L: D5.1 (K), J2.1, SW2.8, U4.4 (L), U6.6 (CANL)
/CAN_RX: U1.47 (PA11), U6.4 (RXD)
/CAN_TX: U1.48 (PA12), U6.1 (TXD)
/GHS1: R11.1, U1.43 (GHS1)
/GHS2: R14.1, U1.40 (GHS2)
/GHS3: R17.1, U1.37 (GHS3)
/GLS1: R12.1, U1.29 (GLS1)
/GLS2: R15.1, U1.30 (GLS2)
/GLS3: R18.1, U1.31 (GLS3)
/MA730_CS: U1.57 (PB6), U5.5 (~CS)
/MA730_CS_2: J3.1, U1.58 (PB7)
/MA730_MISO: J3.3, U1.55 (PB4), U5.7 (MISO)
/MA730_MOSI: J3.2, U1.56 (PB5), U5.4 (MOSI)
/MA730_SCLK: J3.4, U1.54 (PB3), U5.12 (SCLK)
/NRST: C1.1, R2.2, U1.8 (PG10)
/NTC: C17.1, R21.2, TH1.2, U1.12 (PC3)
/OPAMP1_VINM0: C33.1, R22.2, R25.1, U1.16 (PA3), U7.2 (-)
/OPAMP1_VINP: R23.2, R24.1, R42.2, U1.14 (PA1), U7.3 (+)
/OPAMP1_VOUT: C33.2, R25.2, U1.15 (PA2), U7.1
/OPAMP2_VINM0: C34.1, R28.2, R31.1, U1.18 (PA5), U8.2 (-)
/OPAMP2_VINP: R26.2, R27.1, R41.2, U1.20 (PA7), U8.3 (+)
/OPAMP2_VOUT: C34.2, R31.2, U1.19 (PA6), U8.1
/OPAMP3_VINM0: C35.1, R32.2, R39.1, U1.25 (PB2), U9.2 (-)
/OPAMP3_VINP: R29.2, R30.1, R40.2, U1.23 (PB0), U9.3 (+)
/OPAMP3_VOUT: C35.2, R39.2, U1.24 (PB1), U9.1
/PHASE_A: C16.2, Q1.1 (S), Q1.2 (S), Q1.3 (S), Q2.5 (D), R34.1, TP1.1, U1.42 (OUT1)
/PHASE_A_SENSE: R33.1, R34.2, U1.17 (PA4)
/PHASE_B: C24.2, Q3.1 (S), Q3.2 (S), Q3.3 (S), Q4.5 (D), R36.1, TP2.1, U1.39 (OUT2)
/PHASE_B_SENSE: R35.1, R36.2, U1.21 (PC4)
/PHASE_C: C37.2, Q5.1 (S), Q5.2 (S), Q5.3 (S), Q6.5 (D), R38.1, TP3.1, U1.36 (OUT3)
/PHASE_C_SENSE: R37.1, R38.2, U1.22 (PC5)
/SCREF: R3.1, R4.2, U1.52 (SCREF)
/SW1: SW2.4, U1.3 (PC13)
/SW2: SW2.3, U1.4 (PC14)
/SW3: SW2.2, U1.5 (PC15)
/SWCLK: R6.1, U1.50 (PA14)
/SWDIO: R5.1, U1.49 (PA13)
/VBUS_SENSE: C7.1, R7.1, R8.2, U1.13 (PA0)
/VSHUNT1P: Q2.1 (S), Q2.2 (S), Q2.3 (S), R13.1, R23.1
/VSHUNT2P: Q4.1 (S), Q4.2 (S), Q4.3 (S), R16.1, R26.1
/VSHUNT3P: Q6.1 (S), Q6.2 (S), Q6.3 (S), R19.1, R29.1
/WS2812: D7.3 (DIN), U1.45 (PA9)
GND: C1.2, C2.2, C3.2, C4.2, C5.2, C6.2, C7.2, C9.2, C10.2, C11.2, C13.2, C14.2, C15.2, C17.2, C18.2, C19.2, C20.2, C21.2, C22.2, C23.2, C25.2, C26.2, C27.2, C28.2, C29.2, C30.2, C31.2, C32.2, C36.2, C38.2, C39.2, C40.2, C41.2, C42.2, C43.2, C44.2, C45.2, D1.2 (A2), D5.3 (A), D6.2 (A), D7.2 (VSS), D8.2 (VSS), D9.2 (VSS), D10.2 (VSS), D11.2 (VSS), D12.2 (VSS), J1.3, J1.MP (MountPin), J2.MP (MountPin), J3.6, J3.MP (MountPin), R1.2, R4.1, R8.1, R10.2, R13.2, R16.2, R19.2, R22.1, R28.1, R32.1, R33.2, R35.2, R37.2, R40.1, R41.1, R42.1, SW2.5, SW2.6, SW2.7, TH1.1, U1.32 (PGND), U1.65 (VSS), U2.1 (GND), U3.2 (GND), U4.1 (GND), U5.8 (GND), U5.10 (TEST), U5.17 (PAD), U6.2 (GND), U6.8 (STB)
unnamed: D7.1 (DOUT), D8.3 (DIN)
unnamed: D8.1 (DOUT), D9.3 (DIN)
unnamed: D9.1 (DOUT), D10.3 (DIN)
unnamed: D10.1 (DOUT), D11.3 (DIN)
unnamed: D11.1 (DOUT), D12.3 (DIN)
unnamed: J1.1, R5.2
unnamed: J1.2, R6.2
unnamed: Q1.4 (G), R11.2
unnamed: Q2.4 (G), R12.2
unnamed: Q3.4 (G), R14.2
unnamed: Q4.4 (G), R15.2
unnamed: Q5.4 (G), R17.2
unnamed: Q6.4 (G), R18.2
unnamed: R20.2, SW2.1
unnamed: C8.1, U3.1 (BS)
unnamed: C12.2, R9.2, R10.1, U3.3 (FB)
unnamed: C8.2, L1.1, U3.6 (LX)

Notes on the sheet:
CAN
ENTERPRIZE
RM2026
SENSE
MOS
STSPIN32G4
Encoder
OTHER
POWER
Opamp Independent mode 0.01ohm *16 Gain Measure Range: +-30A

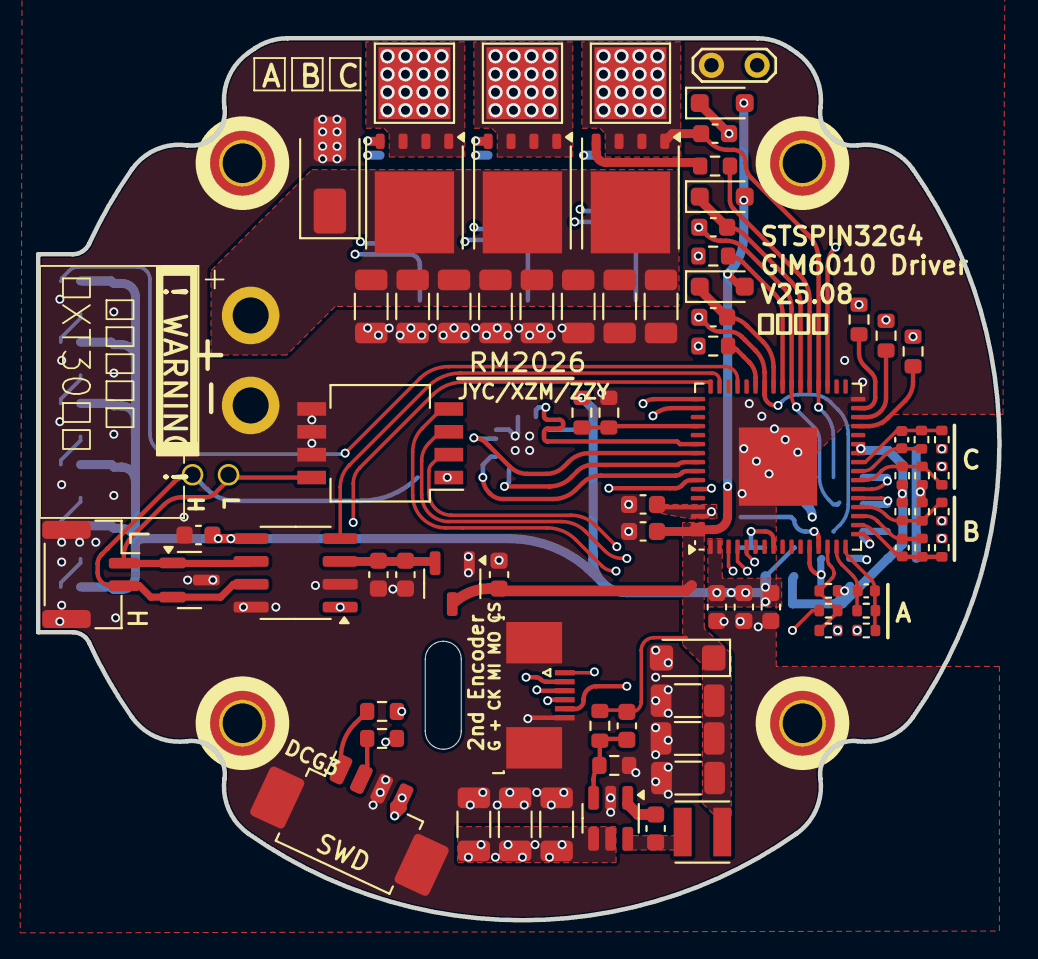
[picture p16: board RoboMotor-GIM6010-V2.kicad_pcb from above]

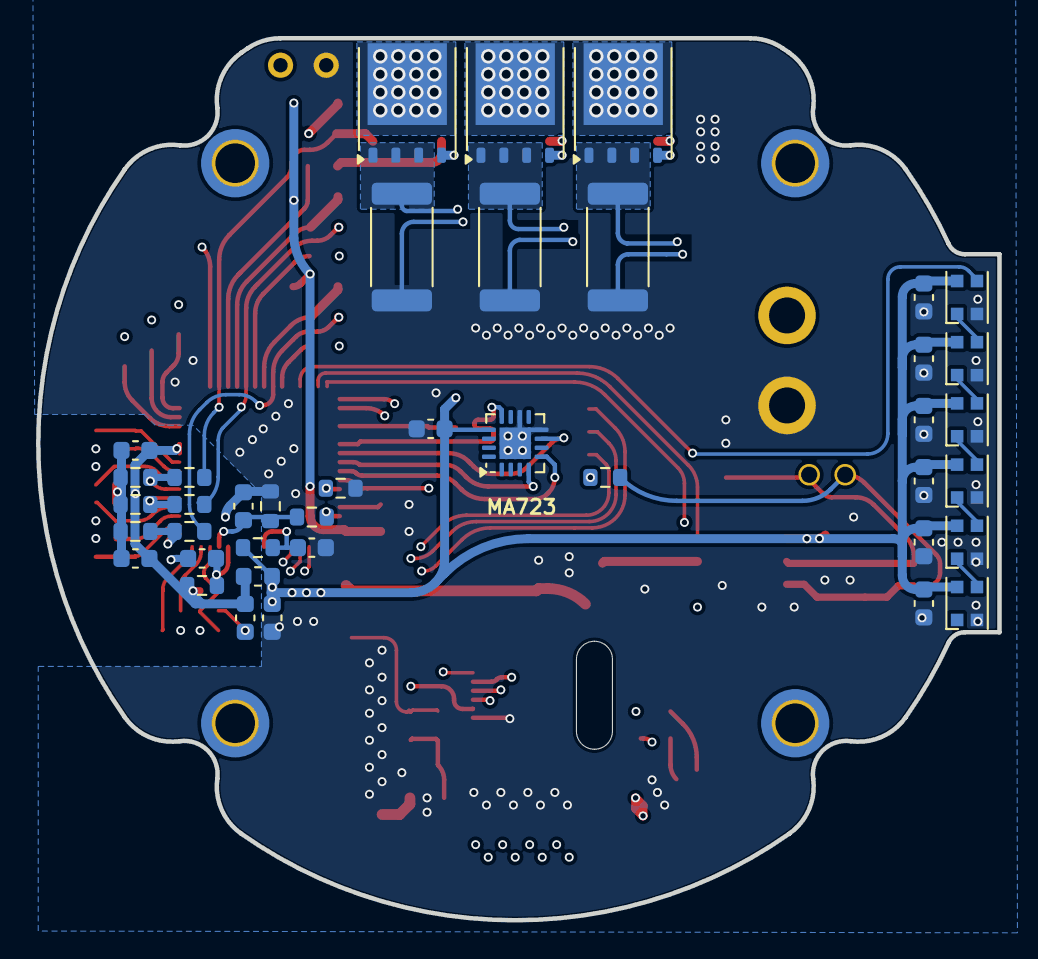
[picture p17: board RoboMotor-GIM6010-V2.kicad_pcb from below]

Board: 4 copper layers, 53.4 x 49.0 mm, 125 parts (40 on the bottom side), 70 nets.

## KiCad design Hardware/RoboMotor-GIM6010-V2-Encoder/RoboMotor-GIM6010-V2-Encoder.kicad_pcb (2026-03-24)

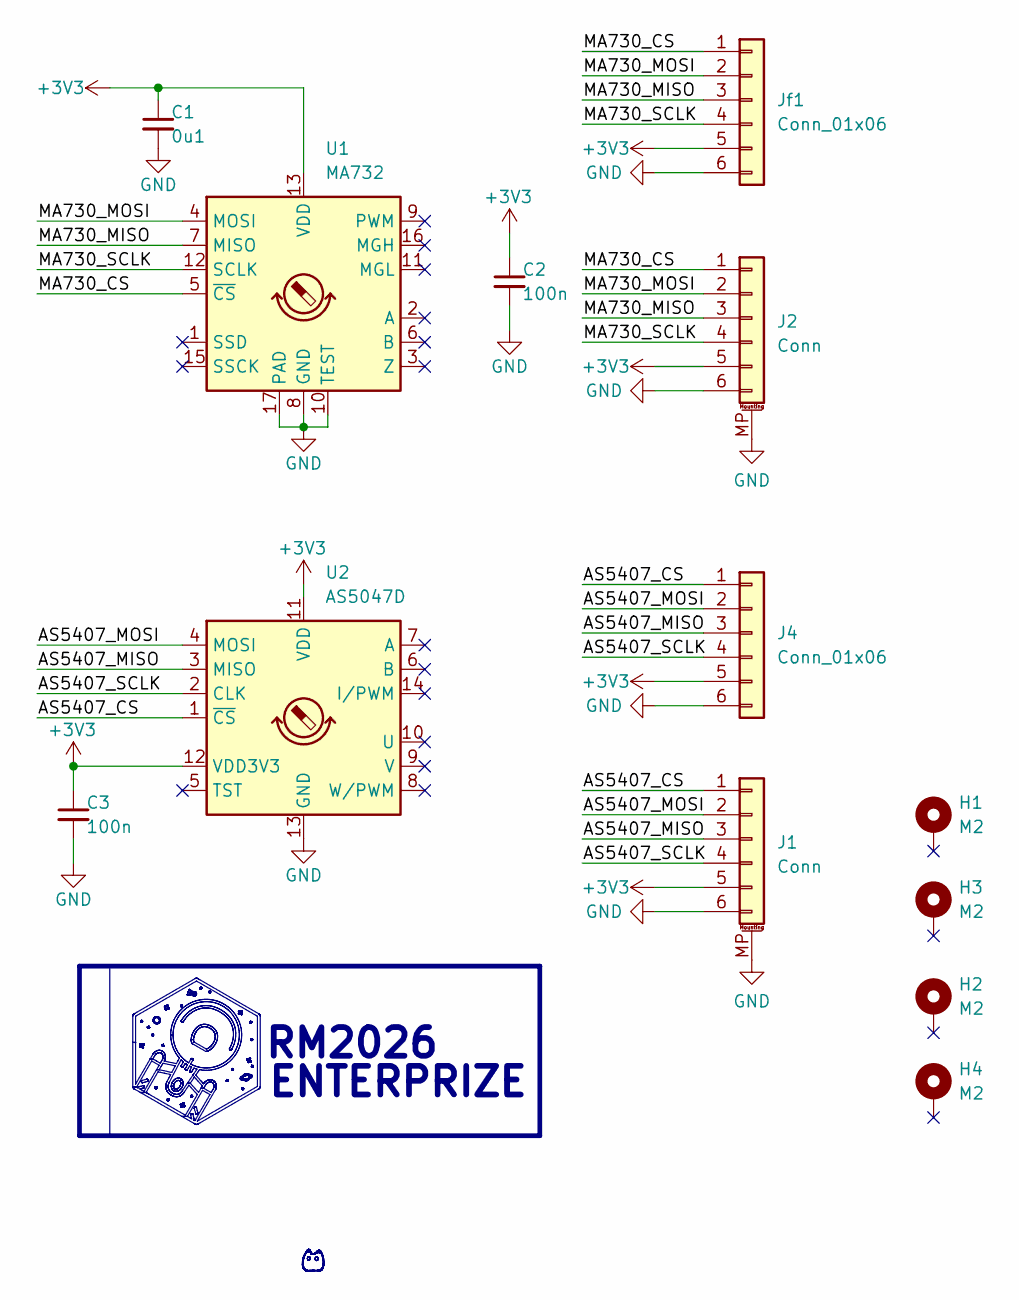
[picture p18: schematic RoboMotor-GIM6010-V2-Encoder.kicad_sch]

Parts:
C1: 0u1; C_0603_1608Metric
C2, C3: 100n; C_0603_1608Metric
H1, H2, H3, H4: M2; MountingHole_2.2mm_M2_DIN965_Pad_TopBottom
J1, J2: Conn; TE_0-1734839-6_1x06-1MP_P0.5mm_Horizontal
J4: Conn_01x06; PinHeader_1x06_P1.27mm_Vertical
Jf1: Conn_01x06; PinHeader_1x06_P1.27mm_Vertical
U1: MA732; QFN-16-1EP_3x3mm_P0.5mm_EP1.75x1.75mm
U2: AS5047D; TSSOP-14_4.4x5mm_P0.65mm

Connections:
+3V3: C1.1, C2.1, C3.1, J1.5, J2.5, J4.5, Jf1.5, U1.13 (VDD), U2.11 (VDD), U2.12 (VDD3V3)
/AS5407_CS: J1.1, J4.1, U2.1 (~CS)
/AS5407_MISO: J1.3, J4.3, U2.3 (MISO)
/AS5407_MOSI: J1.2, J4.2, U2.4 (MOSI)
/AS5407_SCLK: J1.4, J4.4, U2.2 (CLK)
/MA730_CS: J2.1, Jf1.1, U1.5 (~CS)
/MA730_MISO: J2.3, Jf1.3, U1.7 (MISO)
/MA730_MOSI: J2.2, Jf1.2, U1.4 (MOSI)
/MA730_SCLK: J2.4, Jf1.4, U1.12 (SCLK)
GND: C1.2, C2.2, C3.2, J1.6, J1.MP (MountPin), J2.6, J2.MP (MountPin), J4.6, Jf1.6, U1.8 (GND), U1.10 (TEST), U1.17 (PAD), U2.13 (GND)

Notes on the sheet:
ENTERPRIZE
RM2026

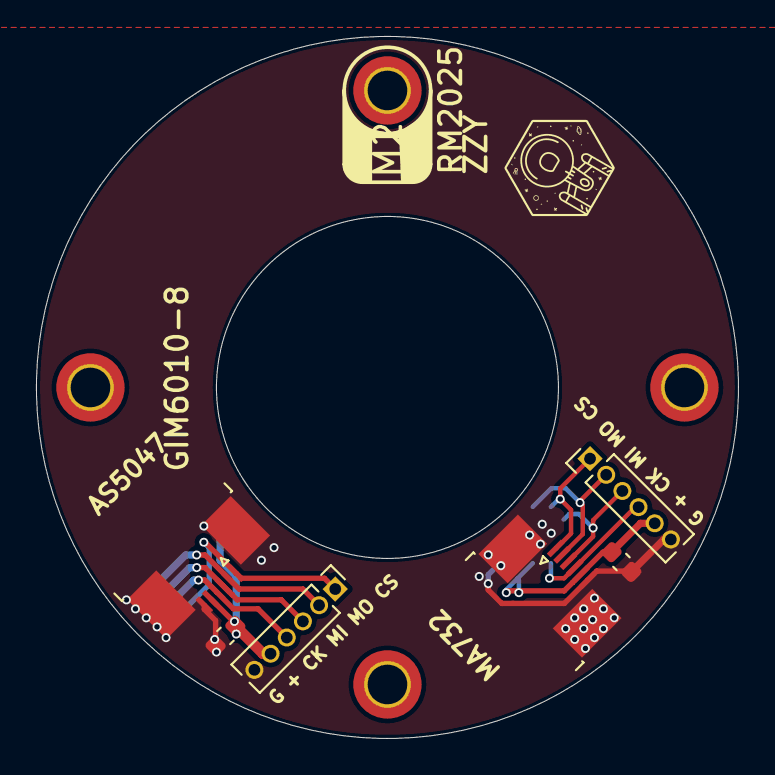
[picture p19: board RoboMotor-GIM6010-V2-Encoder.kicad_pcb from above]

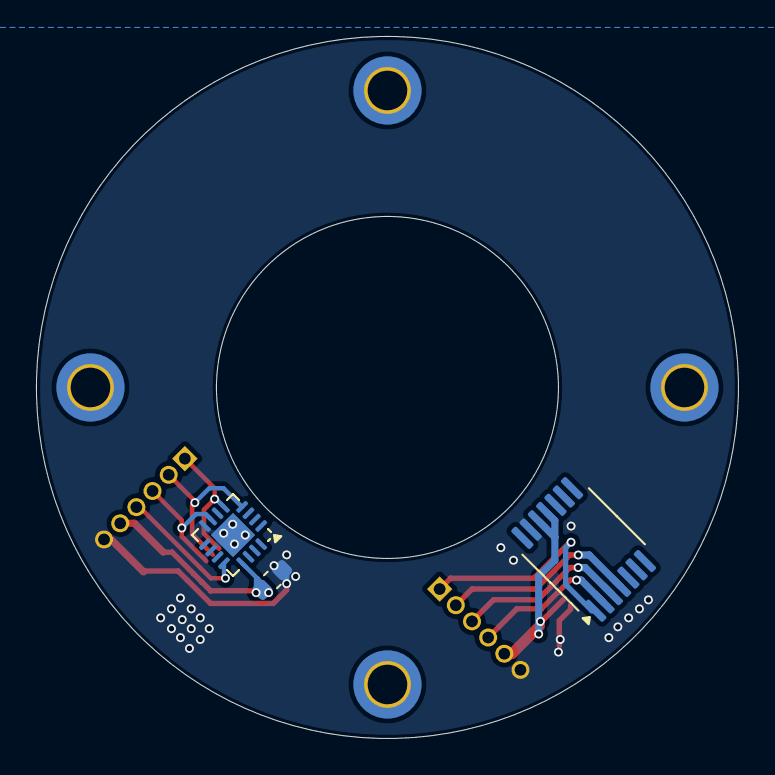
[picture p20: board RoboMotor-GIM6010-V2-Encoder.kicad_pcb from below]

Board: 2 copper layers, 39.0 x 39.0 mm, 13 parts (3 on the bottom side), 10 nets.

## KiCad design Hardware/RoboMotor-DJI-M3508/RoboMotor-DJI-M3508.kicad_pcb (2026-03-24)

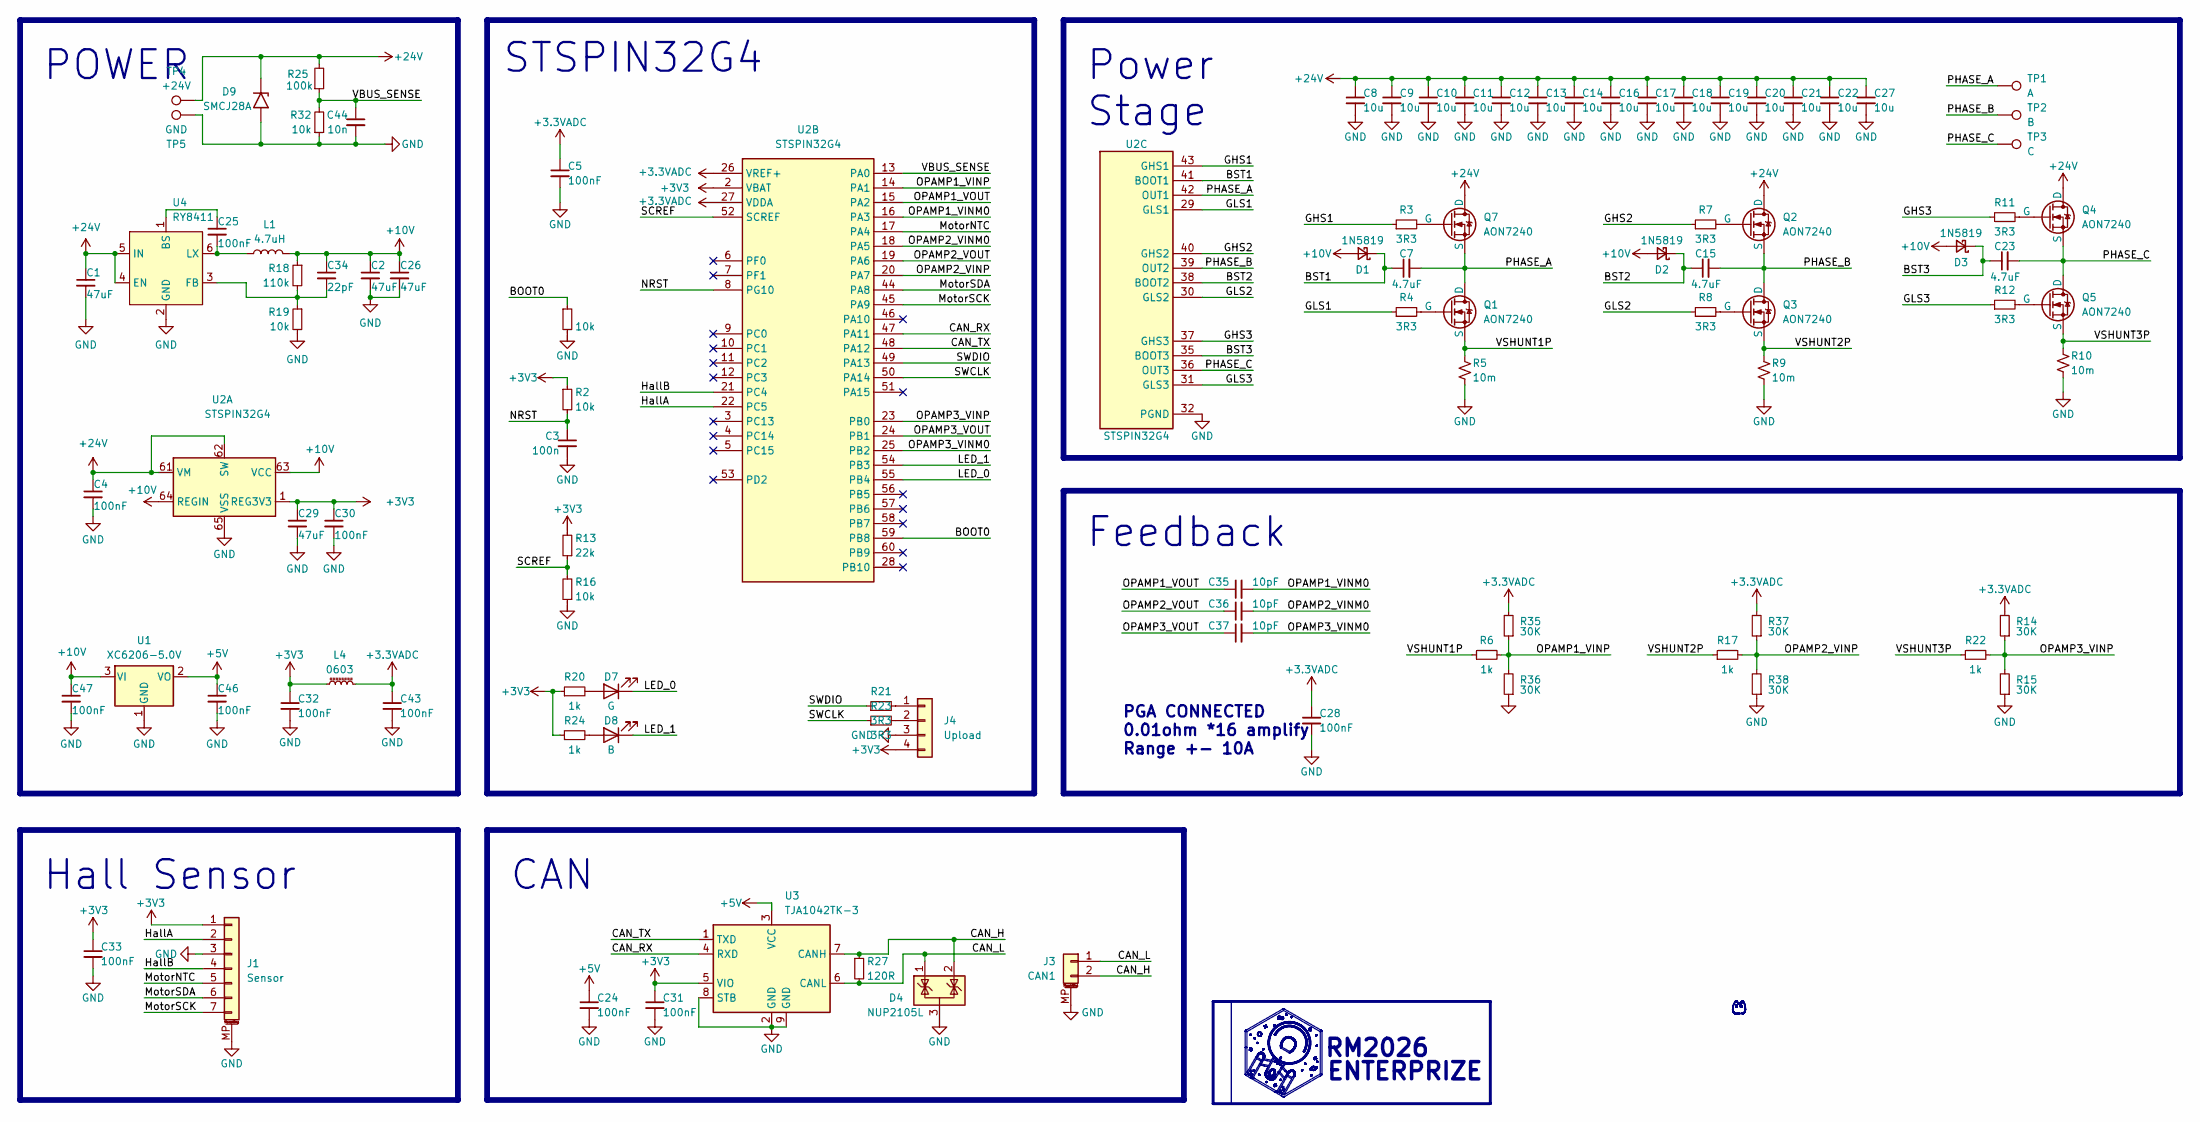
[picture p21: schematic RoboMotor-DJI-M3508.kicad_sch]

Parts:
C1: 47uF; C_1206_3216Metric
C2, C26: 47uF; C_0805_2012Metric
C3: 100n; C_0402_1005Metric
C4, C5, C24, C25, C28, C30, C31, C32, C33, C43, C46, C47: 100nF; C_0402_1005Metric
C7, C15, C23: 4.7uF; C_0402_1005Metric
C8, C9, C10, C11, C12, C13, C14, C16, C17, C18, C19, C20, C21, C22, C27: 10u; C_1206_3216Metric
C29: 47uF; C_0603_1608Metric
C34: 22pF; C_0402_1005Metric
C35, C36, C37: 10pF; C_0402_1005Metric
C44: 10n; C_0402_1005Metric
D1, D2, D3: 1N5819; D_SOD-523
D4: NUP2105L; SOT-23
D7: G; LED_0402_1005Metric
D8: B; LED_0402_1005Metric
D9: SMCJ28A; D_SMA
J1: Sensor; Molex_CLIK-Mate_502386-0770_1x07-1MP_P1.25mm_Horizontal
J3: CAN1; JST_GH_SM02B-GHS-TB_1x02-1MP_P1.25mm_Horizontal
J4: Upload; 1.25Upload
L1: 4.7uH; L_Neosid_SMS-ME3015
L4: 0603; L_0603_1608Metric
Q1, Q2, Q3, Q4, Q5, Q7: AON7240; DFN3x3
R1, R2, R16, R19, R32: 10k; R_0402_1005Metric
R3, R4, R7, R8, R11, R12, R21, R23: 3R3; R_0402_1005Metric
R5, R9, R10: 10m; R_1206_3216Metric
R6, R17, R20, R22, R24: 1k; R_0402_1005Metric
R13: 22k; R_0402_1005Metric
R14, R15, R35, R36, R37, R38: 30K; R_0402_1005Metric
R18: 110k; R_0402_1005Metric
R25: 100k; R_0402_1005Metric
R27: 120R; R_0402_1005Metric
TP1: A; TestPoint_Pad_2.0x2.0mm
TP2: B; TestPoint_Pad_2.0x2.0mm
TP3: C; TestPoint_Pad_2.0x2.0mm
TP4: +24V; TestPoint_Pad_2.5x2.5mm
TP5: GND; TestPoint_Pad_2.5x2.5mm
U1: XC6206-5.0V; SOT-23-3
U2: STSPIN32G4; QFN-64-1EP_9x9mm_P0.5mm_EP4.35x4.35mm
U3: TJA1042TK-3; DFN-8-1EP_3x3mm_P0.65mm_EP1.55x2.4mm
U4: RY8411; SOT-23-6

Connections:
+3.3VADC: C5.1, C28.1, C43.1, L4.2, R14.2, R35.2, R37.2, U2.26 (VREF+), U2.27 (VDDA)
+3V3: C29.1, C30.1, C31.1, C32.1, C33.1, J1.1, J4.4, L4.1, R2.1, R13.2, R20.1, R24.1, U2.1 (REG3V3), U2.2 (VBAT), U3.5 (VIO)
+5V: C24.1, C46.1, U1.2 (VO), U3.3 (VCC)
+10V: C2.1, C26.1, C34.1, C47.1, D1.2 (A), D2.2 (A), D3.2 (A), L1.2, R18.1, U1.3 (VI), U2.63 (VCC), U2.64 (REGIN)
+24V: C1.1, C4.1, C8.1, C9.1, C10.1, C11.1, C12.1, C13.1, C14.1, C16.1, C17.1, C18.1, C19.1, C20.1, C21.1, C22.1, C27.1, D9.1 (A1), Q2.1 (D), Q4.1 (D), Q7.1 (D), R25.2, TP4.1, U2.61 (VM), U2.62 (SW), U4.4 (EN), U4.5 (IN)
/BOOT0: R1.1, U2.59 (PB8)
/BST1: C7.1, D1.1 (K), U2.41 (BOOT1)
/BST2: C15.1, D2.1 (K), U2.38 (BOOT2)
/BST3: C23.1, D3.1 (K), U2.35 (BOOT3)
/CAN_H: D4.2 (K), J3.2, R27.1, U3.7 (CANH)
/CAN_L: D4.1 (K), J3.1, R27.2, U3.6 (CANL)
/CAN_RX: U2.47 (PA11), U3.4 (RXD)
/CAN_TX: U2.48 (PA12), U3.1 (TXD)
/GHS1: R3.1, U2.43 (GHS1)
/GHS2: R7.1, U2.40 (GHS2)
/GHS3: R11.1, U2.37 (GHS3)
/GLS1: R4.1, U2.29 (GLS1)
/GLS2: R8.1, U2.30 (GLS2)
/GLS3: R12.1, U2.31 (GLS3)
/HallA: J1.2, U2.22 (PC5)
/HallB: J1.4, U2.21 (PC4)
/LED_0: D7.1 (K), U2.55 (PB4)
/LED_1: D8.1 (K), U2.54 (PB3)
/MotorNTC: J1.5, U2.17 (PA4)
/MotorSCK: J1.7, U2.45 (PA9)
/MotorSDA: J1.6, U2.44 (PA8)
/NRST: C3.1, R2.2, U2.8 (PG10)
/OPAMP1_VINM0: C35.2, U2.16 (PA3)
/OPAMP1_VINP: R6.2, R35.1, R36.2, U2.14 (PA1)
/OPAMP1_VOUT: C35.1, U2.15 (PA2)
/OPAMP2_VINM0: C36.2, U2.18 (PA5)
/OPAMP2_VINP: R17.2, R37.1, R38.2, U2.20 (PA7)
/OPAMP2_VOUT: C36.1, U2.19 (PA6)
/OPAMP3_VINM0: C37.2, U2.25 (PB2)
/OPAMP3_VINP: R14.1, R15.2, R22.2, U2.23 (PB0)
/OPAMP3_VOUT: C37.1, U2.24 (PB1)
/PHASE_A: C7.2, Q1.1 (D), Q7.3 (S), TP1.1, U2.42 (OUT1)
/PHASE_B: C15.2, Q2.3 (S), Q3.1 (D), TP2.1, U2.39 (OUT2)
/PHASE_C: C23.2, Q4.3 (S), Q5.1 (D), TP3.1, U2.36 (OUT3)
/SCREF: R13.1, R16.2, U2.52 (SCREF)
/SWCLK: R23.1, U2.50 (PA14)
/SWDIO: R21.1, U2.49 (PA13)
/VBUS_SENSE: C44.1, R25.1, R32.2, U2.13 (PA0)
/VSHUNT1P: Q1.3 (S), R5.1, R6.1
/VSHUNT2P: Q3.3 (S), R9.1, R17.1
/VSHUNT3P: Q5.3 (S), R10.1, R22.1
GND: C1.2, C2.2, C3.2, C4.2, C5.2, C8.2, C9.2, C10.2, C11.2, C12.2, C13.2, C14.2, C16.2, C17.2, C18.2, C19.2, C20.2, C21.2, C22.2, C24.2, C26.2, C27.2, C28.2, C29.2, C30.2, C31.2, C32.2, C33.2, C43.2, C44.2, C46.2, C47.2, D4.3 (A), D9.2 (A2), J1.3, J1.MP (MountPin), J3.MP (MountPin), J4.3, R1.2, R5.2, R9.2, R10.2, R15.1, R16.1, R19.2, R32.1, R36.1, R38.1, TP5.1, U1.1 (GND), U2.32 (PGND), U2.65 (VSS), U3.2 (GND), U3.8 (STB), U3.9 (GND), U4.2 (GND)
unnamed: D7.2 (A), R20.2
unnamed: D8.2 (A), R24.2
unnamed: J4.1, R21.2
unnamed: J4.2, R23.2
unnamed: Q1.2 (G), R4.2
unnamed: Q2.2 (G), R7.2
unnamed: Q3.2 (G), R8.2
unnamed: Q4.2 (G), R11.2
unnamed: Q5.2 (G), R12.2
unnamed: Q7.2 (G), R3.2
unnamed: C25.1, U4.1 (BS)
unnamed: C34.2, R18.2, R19.1, U4.3 (FB)
unnamed: C25.2, L1.1, U4.6 (LX)

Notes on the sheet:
Power Stage
CAN
POWER
PGA CONNECTED 0.01ohm *16 amplify Range +- 10A
RM2026
Feedback
Hall Sensor
STSPIN32G4
ENTERPRIZE

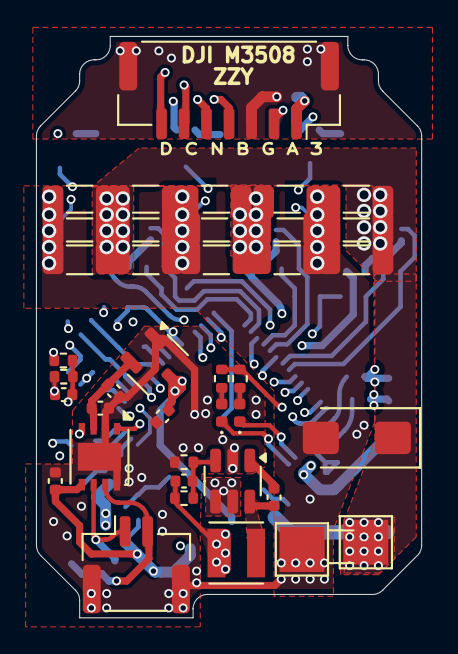
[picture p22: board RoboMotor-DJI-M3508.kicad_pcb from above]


Board: 6 copper layers, 21.4 x 32.3 mm, 98 parts (58 on the bottom side), 60 nets.

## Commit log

2026-03-24 Add Hardware PCB
    [RoboMotor-DJI-M3508.kicad_pcb, RoboMotor-DJI-M3508.kicad_sch, RoboMotor-GIM6010-V2-Encoder.kicad_pcb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]
2026-03-27 GIM6010 CNC Reverse Engineering
    [CNC_BOT.SLDPRT, CNC_TOP.SLDPRT]
